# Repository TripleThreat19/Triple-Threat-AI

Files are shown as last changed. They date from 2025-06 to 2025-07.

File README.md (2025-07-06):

# Triple-Threat: Proyecto Orlando 🤖

---

## 🚀 Categoría: Futuros Ingenieros WRO 2025

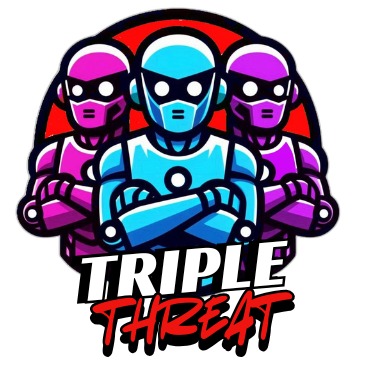
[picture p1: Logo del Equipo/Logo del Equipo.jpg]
Logo del Equipo Triple Threat


---

## 🚀 Presentación del Equipo

Desde que tenemos memoria, la robótica ha sido nuestra pasión. Somos Triple Threat, hermanos trillizos: Carlos, nuestro experto en programación; Valeria, la encargada del diario de ingeniería; y Valentina, la ingeniera mecánica detrás de cada diseño.

Hace dos años, nuestra aventura en la WRO comenzó en la categoría de Deportes Robóticos. No fue cualquier partido, era un tenis doble con una particularidad que lo hacía desafiante: cuatro pelotas en cada lado, una pared en contra y una rampa que agregaba una capa extra de complejidad al campo de juego. Fue un reto estratégico donde aprendimos la importancia de cada detalle, la precisión en el movimiento y la presión del tiempo. El año pasado, la emoción se multiplicó cuando, con mucho esfuerzo y dedicación, logramos clasificar para la etapa internacional en Turquía. Esa experiencia fue inolvidable: conocer a equipos de todo el mundo, sumergirnos en diferentes culturas y, sobre todo, poner a prueba nuestras habilidades en un escenario global.

Ahora, después de esas dos increíbles experiencias, queríamos un nuevo desafío, algo que nos llevara al límite. Queríamos medir hasta dónde hemos crecido, no solo individualmente, sino como equipo. Por eso, decidimos inscribirnos en la categoría de Futuros Ingenieros. Este no es solo otro concurso para nosotros; es la oportunidad perfecta para aplicar todo lo que hemos aprendido, para innovar, para enfrentarnos a problemas complejos y demostrar que nuestra pasión y nuestro trabajo en equipo son más fuertes que nunca. Queremos ver de qué somos capaces cuando la creatividad, la lógica y la camaradería se unen en un robot que redefine los límites.

---

## 📖 Diario de Ingeniería / Documentación Técnica

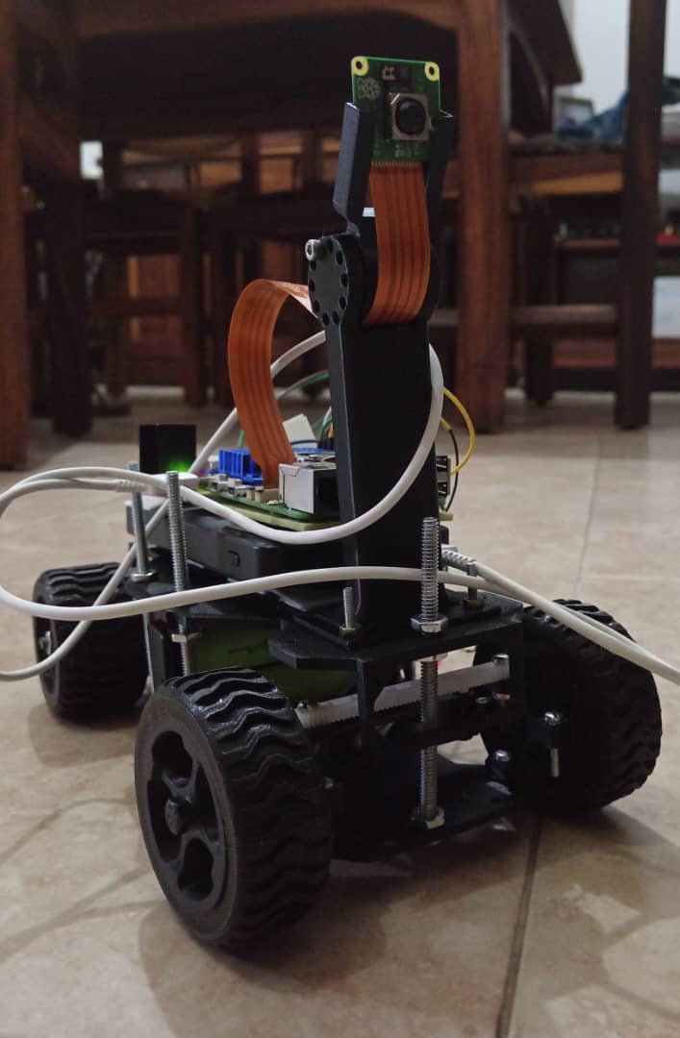
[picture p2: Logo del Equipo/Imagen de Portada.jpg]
Imagen de Portada del Proyecto Orlando (https://github.com/TripleThreat19/Triple-Threat-AI)


Este repositorio centraliza toda la **documentación técnica** del proyecto **Orlando**, una iniciativa desarrollada por el equipo **Triple Threat** para la categoría **Futuros Ingenieros** de la **WRO 2025**. Aquí, desglosamos meticulosamente cada aspecto de nuestro robot: desde el **diseño detallado del vehículo** y la **programación del sistema de control**, hasta la **selección estratégica de componentes** y la **estructura de cableado** implementada para su óptimo funcionamiento.

Cada sección es un reflejo de nuestro **esfuerzo, dedicación y compromiso** como equipo frente a este emocionante desafío. El proyecto Orlando no es solo una solución técnica a un problema propuesto; es el culmen de incontables horas de **trabajo en equipo, investigación profunda, pruebas constantes y mejora continua**, todo impulsado por nuestra **pasión por la robótica y el aprendizaje colaborativo**.

Con este trabajo, nuestro objetivo es doble: no solo buscamos destacar en la competencia, sino también **inspirar a otros jóvenes** a sumergirse en el fascinante mundo de la ingeniería con creatividad, disciplina y un entusiasmo inquebrantable. ¡Esperamos que este diario sea una fuente de aprendizaje y motivación!

---

---

# Problema Identificado: Vehículo Autónomo para Competición "Time Attack" (WRO Futuros Ingenieros)

## Desafío del Reto

El desafío de la **World Robot Olympiad (WRO)** en la categoría de **Futuros Ingenieros** para esta temporada se enfoca en **vehículos autónomos para carreras tipo "Time Attack"**. El objetivo es diseñar, construir y programar un robot capaz de navegar una pista, superar obstáculos específicos y realizar un estacionamiento en paralelo, todo ello buscando el mejor tiempo posible.

## Problemas Clave a Resolver

Hemos identificado los siguientes desafíos técnicos principales que nuestro vehículo debe superar:

### 1. Navegación y Control de Alta Velocidad
* **Seguimiento de Pista Preciso:** El robot necesita un sistema robusto para mantenerse dentro de la pista y seguir la línea con gran exactitud durante múltiples vueltas, optimizando la trayectoria para la velocidad.
* **Control Dinámico de Velocidad:** Mantener la máxima velocidad posible sin perder el control en curvas o secciones complejas es crucial para el "Time Attack".

### 2. Adaptación a Obstáculos Variables

#### Desafío de Muros Interiores Aleatorios:
* **Detección de Muros en Tiempo Real:** El robot debe identificar la posición cambiante de los muros en la pista sin depender de un mapa predefinido.
* **Evasión Eficiente:** Desarrollar algoritmos que permitan al robot rodear los muros rápidamente y sin colisionar, recalculando su ruta sobre la marcha.

#### Desafío de Señales de Tráfico (Pilares Verdes/Rojos):
* **Reconocimiento Visual de Señales:** Implementar un sistema fiable para detectar y diferenciar los pilares verdes (girar a la izquierda) y rojos (girar a la derecha).
* **Decisión y Maniobra Basada en Señal:** El robot debe ajustar su posición en el carril según la señal detectada, ejecutando la maniobra con precisión para no desplazar los pilares.

### 3. Maniobra de Estacionamiento en Paralelo
* **Detección de Zona de Aparcamiento:** El robot necesita identificar el espacio de estacionamiento designado al finalizar las vueltas.
* **Ejecución Precisa del Paralelo:** Realizar una secuencia compleja de movimientos coordinados para estacionar el vehículo correctamente en un espacio reducido.

---

## 🎯  Nuestro Enfoque

Nuestro proyecto busca desarrollar un vehículo autónomo que integre **percepción avanzada del entorno, toma de decisiones dinámica y control de movimiento de alta precisión**. Para lograr esto, utilizaremos una **cámara Raspberry Pi AI** para el procesamiento visual y la detección de elementos clave en la pista, conectada a una **Raspberry Pi** que actuará como el cerebro principal para la lógica de control, la planificación de trayectoria y la ejecución de maniobras. Esta combinación nos permitirá abordar eficazmente los desafíos de navegación, adaptación a obstáculos variables y la maniobra final de estacionamiento, con el objetivo de lograr los mejores tiempos en la competición.

---

## 🛠️ Factor de Ingeniería / Diseño del Prototipo

---

## 1. Mecánica del Robot

El diseño mecánico se enfoca en una estructura **robusta y ligera**, optimizada para la distribución del peso y la integración de todos los componentes electrónicos y motrices.

### 1.1. Componentes Clave

* **Chasis**: Es la base del robot. Su diseño está pensado para soportar todos los componentes y asegurar la **rigidez estructural**. La forma y el material (generalmente polímeros resistentes o aleaciones ligeras, según el **modelo 3D**) se seleccionan según la aplicación específica del robot.

* **Tren de Rodaje**: Se compone de un mínimo de cuatro ruedas. Las **ruedas delanteras** son las encargadas de la **dirección**, mientras que las **ruedas traseras** actúan como propulsoras, brindando el empuje necesario para el movimiento. 

---

## 2. Sistema de Dirección

El sistema de dirección es fundamental para la **maniobrabilidad** del robot, imitando el principio de un automóvil. Se basa en el movimiento angular de las **ruedas delanteras**.

### 2.1. Componentes Principales

* **Ruedas Delanteras Direccionales**: Estas ruedas giran alrededor de un eje vertical (similar al pivote de dirección de un coche) para modificar la trayectoria del robot. Ambas **ruedas delanteras direccionales** están interconectadas y se mueven en un ángulo coordinado gracias a un **mecanismo de dirección**.

* **Mecanismo de Dirección**: Este sistema, detallado en el **modelo 3D**, es una simple barra de acoplamiento que conecta ambas ruedas delanteras
  
* **Servomotor**: Un servomotor de alta precisión, es el responsable de ejecutar el movimiento angular de las **ruedas delanteras direccionales**. Este motor recibe las señales de control de la tarjeta controladora (Rasberry PI) y las traduce en el ángulo de giro deseado. La correcta ubicación y el acoplamiento de este servomotor con el mecanismo de dirección son aspectos críticos en el diseño **3D** para garantizar un movimiento fluido y sin holguras.

* **Rasberry PI 5**: La tarjeta controladora del robot Rasberry PI 5 es la encargada de enviar las señales al servomotor para ajustar el ángulo de las **ruedas delanteras direccionales**. Este controlador puede recibir entradas de la Camara Rasberry PI AI para determinar la dirección que se desea tomar.

---

## 3. Funcionamiento General

Para que el robot pueda moverse y girar eficientemente, el sistema opera de la siguiente manera:

* **Propulsión**: Los motores acoplados a las **ruedas traseras** (o un motor diferencial para ambas) giran para impulsar el robot hacia adelante o hacia atrás. La velocidad se regula mediante la potencia suministrada a estos motores.

* **Dirección**: Para iniciar un giro, la Rasberry PI 5 envía una señal al **servomotor**. El servomotor, a su vez, activa el mecanismo de dirección, lo que provoca el cambio en el ángulo de las **ruedas delanteras direccionales**. El grado de giro de estas ruedas determina directamente el radio de giro del robot.

* **Coordinación**: La clave para un movimiento óptimo reside en la **coordinación** entre la velocidad de las ruedas propulsoras y el ángulo de las **ruedas delanteras direccionales**. Para ejecutar giros cerrados, las ruedas delanteras se angulan más, y la velocidad de las ruedas traseras puede ajustarse para facilitar la maniobra y asegurar un giro suave y controlado.

---

Este diseño, meticulosamente modelado en **3D**, permite una visualización detallada y una optimización exhaustiva de la ergonomía, la resistencia y la funcionalidad del robot antes de proceder con su construcción física. Esto asegura un rendimiento óptimo en todos los aspectos de su mecánica y dirección.

---

## Debate Técnico sobre la Gestión de la Movilidad

### 1. Selección e Implementación de Motores

Para la propulsión del robot utilicé un motor DC con encoder, ya que me permite medir la velocidad angular y la posición de cada rueda, lo cual es clave para controlar con precisión la trayectoria. Este motor se seleccionó por su buen equilibrio entre par (torque) y velocidad para una plataforma de tamaño medio (~1.5 a 2 kg de peso total).

El encoder facilita técnicas de control como PID, permitiendo mantener una velocidad constante incluso con cambios en el terreno o peso del robot.

Para el sistema de dirección utilicé un servomotor de rotación limitada (180°). Este tipo de actuador me permite posicionar con precisión las ruedas delanteras en distintos ángulos, lo que se traduce en giros más suaves y exactos. Elegí un servo de alto torque (más de 10 kg·cm), suficiente para girar ambas ruedas mediante la barra de acoplamiento sin generar vibraciones o juego mecánico.

### 2. Principios de Ingeniería Aplicados

- Velocidad:Se estimó una velocidad objetivo de 0.5 a 1 m/s, adecuada para pruebas y recorridos controlados en escenarios de competencia.
- Par (torque): Los motores deben superar la inercia del robot y el rozamiento del suelo. Para eso, se eligió un motor con un torque mínimo de 2 kg·cm en las ruedas traseras.
- Potencia: La potencia eléctrica se dimensionó en función del consumo del motor DC (~6W por motor) y el servomotor (~2-3W en carga), permitiendo alimentar el sistema con una batería Li-ion de 7.4V.

### 3. Diseño y Selección del Chasis

El chasis fue diseñado en CAD 3D para ser liviano, resistente y fácil de imprimir en una impresora 3D FDM. Utilicé PLA reforzado como material principal por su buena relación rigidez/peso. La forma del chasis favorece la distribución de peso centrada, con espacio suficiente para el servo, motores, controlador y batería.

### 4. Montaje de Componentes

- El chasis impreso contiene ranuras específicas para montar los motores DC y sus reductoras usando tornillos M3.
- El servo de dirección se acopla con dos tornillos a un soporte elevado en el centro del eje delantero.
- Las ruedas delanteras están conectadas por una barra rígida impresa en 3D que transmite el movimiento angular del servo.
- La Raspberry Pi 5, el controlador motor y la batería se fijan al chasis mediante bridas plásticas o tornillos autorroscantes en zonas ya previstas en el diseño.

---

### Control del Movimiento (Actuadores):

Motores Modificadores Ópticos Makeblock 180: Estos motores son los encargados de la propulsión del robot, conectados a las ruedas traseras. Incluyen codificadores ópticos que nos dan retroalimentación precisa sobre la velocidad y la distancia recorrida, información vital para la odometría y un control de movimiento exacto.

Puente H: Funciona como la interfaz de potencia entre la Raspberry Pi 5 y los motores Makeblock 180. Permite a la Pi controlar la dirección y la velocidad de los motores (mediante PWM) con señales de bajo voltaje.

Servomotor (Dirección): Este servomotor es crucial para el control preciso del ángulo de las ruedas delanteras directrices. La Raspberry Pi 5 le envía señales PWM para posicionar las ruedas con exactitud, permitiendo giros controlados y suaves.

Percepción del Entorno (Sensores):

Raspberry Pi AI Camera: Este es el principal sensor visual del robot. Conectada a la Raspberry Pi 5, nos permite implementar visión por computadora y algoritmos de Inteligencia Artificial. La cámara procesa el entorno para:

Detección y Reconocimiento de Objetos: Identifica obstáculos, marcas o elementos clave en el entorno.

Seguimiento de Trayectorias: Percibe líneas o caminos a seguir.

Análisis Espacial: Comprende la profundidad y la disposición de los elementos.
La potente Raspberry Pi 5 puede procesar estos datos de imagen en tiempo real, permitiendo al robot tomar decisiones informadas sobre su navegación y acciones.

Software de Control: Todo el sistema lo gestiona el software que se ejecuta en la Raspberry Pi 5, desarrollado principalmente en Python. Este software integra las lecturas de los codificadores y la cámara, procesa la información y genera las señales de control para el Puente H y el servomotor, coordinando así todos los aspectos del movimiento y la interacción del robot con su entorno.

---

# 🤖 Sistema de Rueda y Eje para Nuestro Robot ⚙️

¡Bienvenidos a la sección de hardware de nuestro proyecto! Aquí explicaremos cómo se ensamblan las piezas clave para el movimiento de nuestro robot. La imagen de arriba muestra un "despiece" de los componentes esenciales que conforman una de las unidades de rueda.

---

### Visión General del Ensamblaje

Este sistema está diseñado para proporcionar una rotación fluida y robusta, fundamental para la locomoción de nuestro robot. Cada componente juega un papel crucial en la durabilidad y eficiencia del movimiento.

Es importante destacar que este diseño en particular está pensado para las ruedas delanteras de nuestro robot, actuando como las ruedas directrices. Esto significa que estas unidades serán responsables de la dirección del vehículo. Las ruedas traseras, por su parte, serán las que vayan impulsadas directamente por un motor, complementando este sistema para mejorar significativamente la movilidad y la capacidad de maniobra de nuestro vehículo.

---

### Desglose del Proceso de Montaje

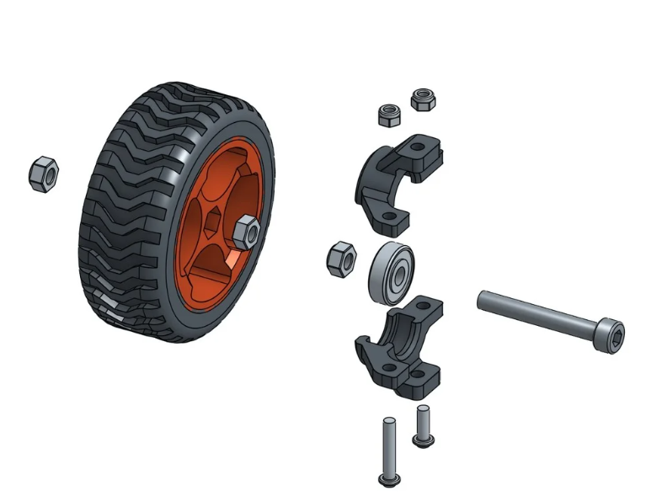
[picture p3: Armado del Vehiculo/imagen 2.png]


El montaje de este subsistema se concibe en una secuencia lógica que asegura la correcta funcionalidad y alineación de las partes:

1.  **Eje y Rodamiento:**
    El punto de partida es el **eje**, un elemento central sobre el cual se montará el **rodamiento**. Este rodamiento es una pieza ingenieril clave, cuya función principal es minimizar la fricción, permitiendo que el eje (y, por ende, la rueda) gire con la mayor suavidad posible y con un mínimo desgaste.

2.  **Soporte del Rodamiento:**
    Una vez que el rodamiento está posicionado en el eje, ambos se alojan dentro del **soporte de rodamiento**. Este soporte se compone de dos mitades que se unen, encapsulando y asegurando el rodamiento en su lugar. La unión de estas dos secciones se logra mediante el uso de **tornillos y tuercas más pequeños**, garantizando que el rodamiento quede firmemente contenido, pero con libertad para girar sobre el eje.

3.  **Fijación de la Rueda:**
    Con el eje y el conjunto de rodamiento/soporte listos, la **rueda** se desliza sobre el extremo libre del eje. Para asegurar que la rueda no se desplace ni se suelte durante el funcionamiento de nuestro robot, se utiliza una **tuerca adicional** que se rosca firmemente en el extremo del eje, fijando la rueda en su posición adecuada.

4.  **Integración en el Chasis del Robot:**
    Finalmente, este ensamblaje completo (compuesto por la rueda, el eje, el rodamiento y su soporte) se integra directamente en la estructura principal de nuestro robot. El diseño del **soporte de rodamiento** incluye puntos de montaje que permiten su fijación segura al chasis o a los brazos de suspensión, si los tuviera. Esta integración no solo proporciona el anclaje físico, sino que también establece el punto de pivote exacto para la rotación de la rueda, siendo esencial para la dinámica de movimiento de nuestro robot.

---

# 🤖 Distribución de Componentes en el Chasis del Robot ⚙️

Nuestro chasis ha sido meticulosamente diseñado para una distribución específica de componentes, buscando optimizar el centro de gravedad y facilitar el proceso de montaje. A continuación, detallamos la ubicación estratégica de los elementos principales:

---

### Colocación de Componentes Clave en la Primera Placa:

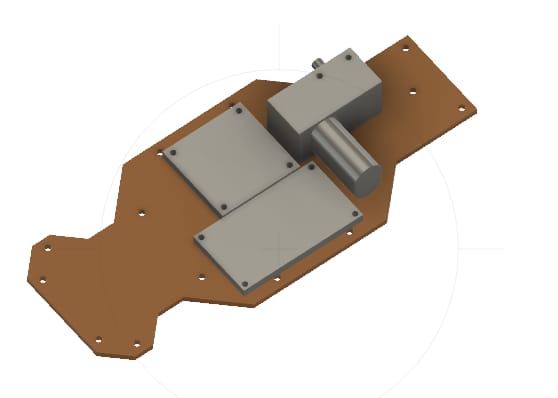
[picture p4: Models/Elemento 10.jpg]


* **Motor:** Se ubica y fija en la parte trasera del chasis. Esta posición estratégica ayuda a concentrar el peso, optimizando la tracción y el balance general del robot.

* **Baterías (Pilas):** Se colocan centralmente en el chasis y se aseguran mediante tornillos. Esta disposición es crucial para lograr una distribución equilibrada del peso, lo que mejora significativamente la estabilidad y la maniobrabilidad del vehículo.

* **Regulador de Voltaje (Regulador):** Aunque no es visible en la disposición general, se situará típicamente cerca de las baterías. Su función es regular el voltaje de entrada para alimentar de forma estable y segura el resto de la electrónica de control del robot.

* **Puente H:** Este componente clave se colocará lo más próximo al motor posible. Esta cercanía minimiza la longitud del cableado, lo que reduce las pérdidas de energía y optimiza el control de dirección y velocidad del motor.

* **Servomotor: Este componente se ubicará en la parte delantera del chasis. Su función principal es controlar el mecanismo de dirección de las ruedas delanteras, permitiendo al robot cambiar de trayectoria con precisión
---

🤖 Ensamblaje del Robot: Distribución de Componentes en el Chasis ⚙️
Nuestro chasis ha sido meticulosamente diseñado para una distribución estratégica de componentes, buscando optimizar el centro de gravedad, la funcionalidad y la facilidad de montaje. A continuación, detallamos la ubicación pensada para los elementos clave:

---

Disposición de Componentes de Percepción y Procesamiento (Segundo Piso):

Estos componentes vitales para la inteligencia y operación del robot se alojarán en una placa superior o "segundo piso", que se montará sobre el chasis principal, aprovechando estructuras como las mostradas en "Elemento 11.jpg".

---

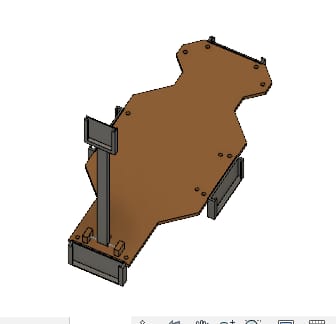
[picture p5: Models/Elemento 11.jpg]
)

Soporte Frontal Vertical (Cámara y Módulo): Esta estructura, parte del segundo piso o conectada a él, está diseñada específicamente para montar la cámara y su módulo adicional en la parte frontal elevada. Su posición estratégica garantiza un campo de visión despejado y alto, crucial para tareas como la detección de obstáculos, navegación y mapeo ambiental.

Espacio Inferior del Segundo Piso (Raspberry Pi y Puente H): En la zona inferior de este segundo nivel (o sobre la superficie de esta placa superior) se destinará el espacio para el Powerbank y la Raspberry Pi. Esta ubicación es fundamental para mantener el "cerebro" del robot (Raspberry Pi) y su fuente de energía suplementaria (Powerbank) accesibles, a la vez que se optimiza el cableado y se minimiza la altura total, contribuyendo al centro de gravedad general del conjunto.

---

# Electrónica

---

Nuestro sistema electrónico, que impulsa y controla cada movimiento de nuestro robot, está cuidadosamente ensamblado con los siguientes elementos clave:
-	Raspberry Pi 5
-	Raspberry Pi AI Camera
-	Servomotor
-	Motor Modificador Óptico Makeblock 180
-	Puente H
- Regulador de Voltaje
-	Baterías
-	Switch
-	Power Bank 

A continuación, se presentará el Diagrama de Cableado que ilustra cómo estos componentes se interconectan para funcionar en armonía.

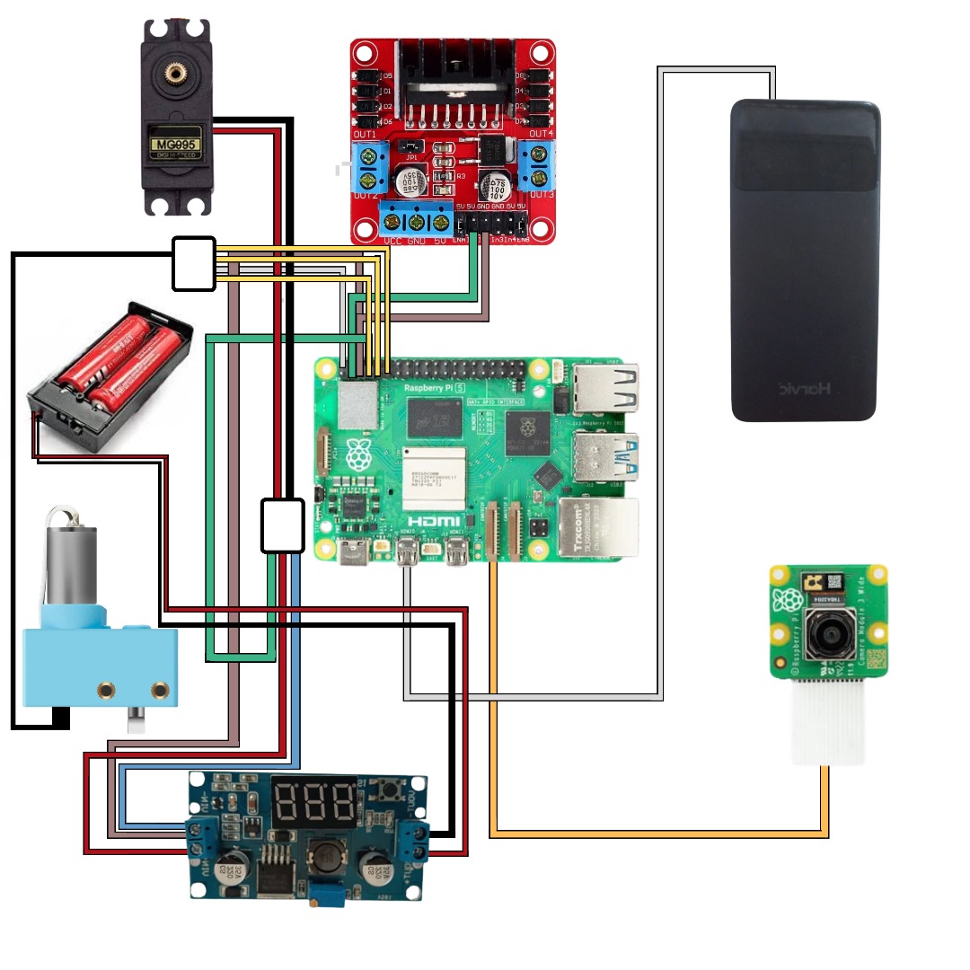
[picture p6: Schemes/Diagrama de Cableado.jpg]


Explicación del Diagrama Expuesto

Raspberry Pi: Es la computadora principal del sistema. Recibe información de algunos componentes y envía órdenes a otros.

Power Bank: Este es la fuente de energía exclusiva para la Raspberry Pi. Le suministra la electricidad necesaria para funcionar.

Baterías: Estas baterías son la fuente de energía exclusiva para los motores. Suministran electricidad al Módulo Regulador de Voltaje y al Módulo de Driver de Motor.

Módulo de Driver de Motor: Este módulo se conecta a la Raspberry Pi (para recibir órdenes) y a las baterías (para obtener energía). Se usa específicamente para controlar el motor DC con encoder.

Servo Motor: Este motor puede moverse a posiciones específicas y se controla a través del drive.

Motor DC con Encoder: Este es un motor que gira continuamente, y el "encoder" le permite a la Raspberry Pi saber exactamente qué tan rápido está girando o qué posición tiene. También se controla a través del driver del motor.

Módulo Regulador de Voltaje: Este módulo toma la energía de las baterías (las rojas) y la ajusta a un voltaje específico que necesita el servomotor, asegurando que reciba la cantidad correcta de energía de manera estable. 

Cámara: Esta cámara se conecta directamente a la Raspberry Pi. Permite a la Raspberry Pi "ver" y capturar imágenes o video.

****
---

### 💡 Componentes del Vehículo

Hemos seleccionado cuidadosamente cada componente para asegurar el máximo rendimiento y fiabilidad de nuestro robot. A continuación, detallamos los elementos esenciales que dan vida a nuestro proyecto.

#### 🧠 Raspberry Pi 5

La **Raspberry Pi 5** es el cerebro de nuestro sistema, definida por la misma Raspberry Pi Foundation como una **PC de bajo coste del tamaño de una tarjeta de crédito**. Permite explorar el mundo de la informática y aprender lenguajes de programación como Scratch y Python, siendo una herramienta increíblemente versátil.

---
**_Características Destacadas:_**

* **CPU de alto rendimiento:** Procesador Broadcom BCM2712 Quad-core Arm Cortex-A76 a 2.4 GHz, ofreciendo un gran poder de procesamiento.
* **GPU avanzada:** GPU VideoCore VII para capacidades gráficas y de procesamiento de visión mejoradas.
* **Memoria RAM generosa:** Disponible con hasta 8GB de RAM LPDDR4X-4267, ideal para multitarea y aplicaciones exigentes.
* **Conectividad versátil:** Incluye Wi-Fi 5 de doble banda, Bluetooth 5.0 y Gigabit Ethernet para una comunicación robusta.
* **Almacenamiento de alta velocidad:** Soporte para tarjetas microSD de alta velocidad y una interfaz PCIe 2.0 x1 para SSDs M.2 externos (vía adaptador).
* **Salida de video dual:** Dos puertos micro HDMI que soportan hasta 4K a 60Hz.
* **Puertos USB 3.0:** Dos puertos USB 3.0 para conectar periféricos de alta velocidad.
* **Conectores MIPI duales:** Dos transceptores MIPI de 4 carriles para hasta dos cámaras o pantallas.
* **Control de ventilador:** Conector dedicado para un ventilador PWM, asegurando un rendimiento óptimo bajo cargas intensas.

---

La **Raspberry Pi 5** es ideal para nuestro robot por su **gran potencia de procesamiento para IA y visión**, lo que nos permite implementar algoritmos complejos. Su **amplia RAM** asegura una multitarea eficiente y su **conectividad avanzada** facilita la comunicación. Además, el **almacenamiento SSD ultrarrápido** y los **conectores MIPI duales para cámaras** son fundamentales para la percepción y toma de decisiones en tiempo real, garantizando un robot de **alto rendimiento y gran fiabilidad**.

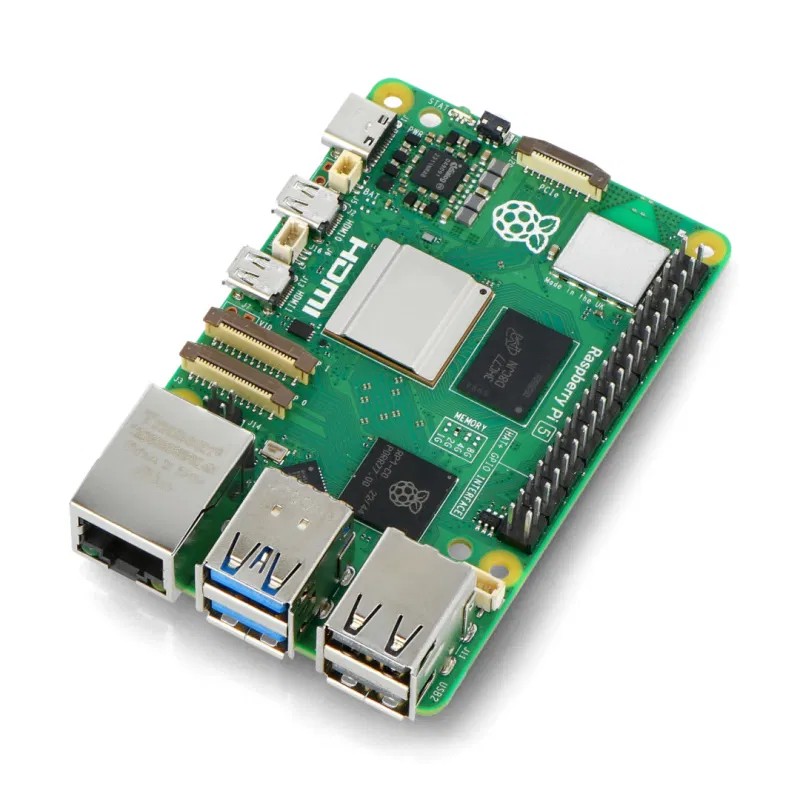
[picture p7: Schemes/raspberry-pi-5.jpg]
Raspberry Pi 5


#### 🔌 Puente H

Un **Puente H** es un circuito electrónico crucial que nos permite **invertir la polaridad de la tensión** aplicada a una carga, comúnmente un motor de corriente continua. Esto se logra mediante la disposición de cuatro interruptores (transistores o relés) que permiten el flujo de corriente en dos direcciones opuestas, controlando así el sentido de giro del motor.

---
**_Características Esenciales:_**

* **Control del sentido de giro:** Permite invertir la polaridad del voltaje aplicado a un motor codificador Óptico, facilitando su rotación hacia adelante o hacia atrás.
* **Control de velocidad:** Al integrar una señal de Modulación por Ancho de Pulso (PWM), puede variar la velocidad del motor de manera eficiente.
* **Capacidad de corriente y voltaje:** Cada Puente H está diseñado para manejar un rango específico, crucial para que coincida con los requisitos del motor y evitar daños.
* **Protecciones integradas:** Muchos puentes H comerciales incluyen protecciones contra sobrecorriente, cortocircuitos y sobrecalentamiento, aumentando la seguridad y durabilidad.
* **Compatibilidad con microcontroladores:** Son fácilmente controlables por microcontroladores como la Raspberry Pi o Arduino, simplificando la lógica de control del motor.
* **Aislamiento y protección del microcontrolador:** Actúa como una interfaz de potencia, protegiendo los componentes de control sensibles de las altas corrientes y ruidos generados por el motor.

---

El **Puente H** es fundamental para nuestro robot porque permite el **control total del motor**: puede cambiar el sentido de giro (adelante/atrás) y, con PWM, controlar la velocidad con precisión. Además, actúa como un **escudo protector para el motor**, aislando los componentes sensibles y garantizando la fiabilidad y seguridad del sistema.

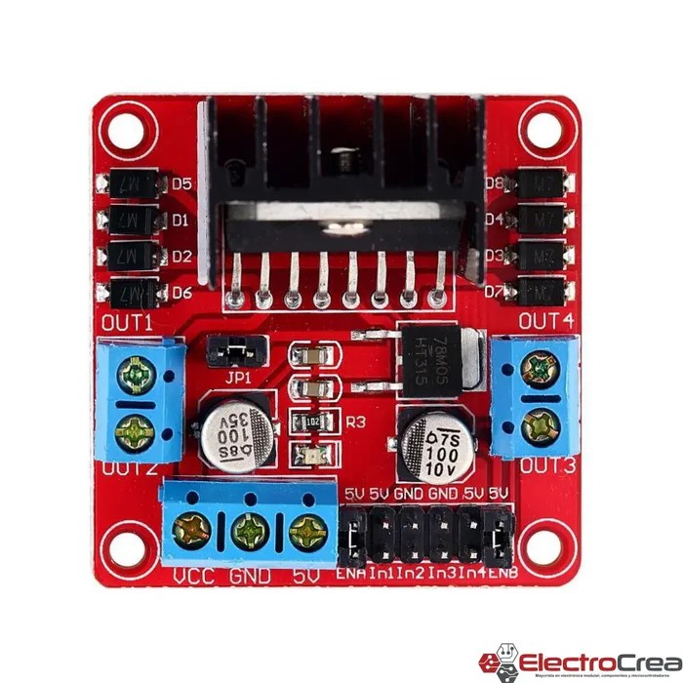
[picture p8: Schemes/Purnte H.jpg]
Puente H


#### 📸 Raspberry Pi AI Camera

La **Raspberry Pi AI Camera** está específicamente diseñada para aprovechar el **procesamiento avanzado de inteligencia artificial (IA)** en dispositivos Raspberry Pi, especialmente cuando se combina con hardware de aceleración como el Hailo AI Module.

---
**_Características Sobresalientes:_**

* **Procesamiento de IA en el chip (Edge AI):** Realiza la inferencia de redes neuronales directamente en el sensor Sony IMX500, liberando la Raspberry Pi principal de esta carga computacional. Esto permite IA en tiempo real con baja latencia.
* **Sensor de alta resolución:** Cuenta con un sensor de 12.3 megapíxeles (4056 x 3040 píxeles), capturando imágenes detalladas.
* **Salida de metadatos de tensor:** Además de la imagen, la cámara puede enviar directamente los resultados del procesamiento de IA, simplificando la integración con otras aplicaciones.
* **Compatibilidad y enfoque manual:** Se conecta vía CSI estándar con todas las Raspberry Pi compatibles y permite ajustar manualmente el enfoque para diversas aplicaciones.
* **Reducción de latencia y ancho de banda:** Los datos procesados de IA (como la detección de objetos) se generan directamente en la cámara, minimizando la latencia y reduciendo significativamente el ancho de banda necesario en el bus de datos CSI.

---

La **Raspberry Pi AI Camera** es fundamental para nuestro robot porque permite la **IA en el borde**, procesando visión directamente en el chip. Esto libera recursos de la Pi 5, reduce la latencia y la necesidad de ancho de banda. Su **alta resolución** y la capacidad de enviar **metadatos de IA pre-procesados** simplifican el desarrollo. Además, es **energéticamente eficiente**, clave para la autonomía del robot. En definitiva, convierte a nuestro robot en un agente **inteligente y reactivo** capaz de percibir e interpretar su entorno de forma autónoma.

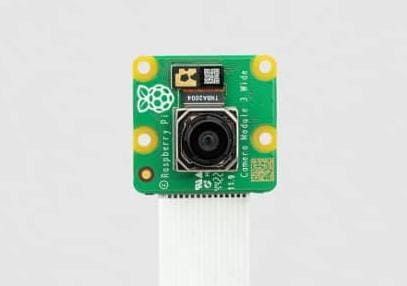
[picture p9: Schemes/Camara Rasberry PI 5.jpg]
La Raspberry Pi AI Camera


(AC) convencionales por su capacidad de **controlar con precisión su posición angular, velocidad y, en algunos casos, su aceleración**. Piensa en él como un motor que no solo gira, sino que sabe exactamente dónde está y puede ir a una posición específica y mantenerla, incluso si hay una fuerza externa que intenta moverlo.

---

Servomotor
Un servomotor es un tipo de motor especial que se diferencia de los motores de corriente continua (DC) o alterna (AC) convencionales por su capacidad de controlar con precisión su posición angular, velocidad y, en algunos casos, su aceleración. Piensa en él como un motor que no solo gira, sino que sabe exactamente dónde está y puede ir a una posición específica y mantenerla, incluso si hay una fuerza externa que intenta moverlo.

---

**_Características Principales:_**

* **Control de Posición Preciso:** Esta es su característica principal. A diferencia de un motor DC que gira libremente cuando se le aplica voltaje, un servomotor puede ser instruido para moverse a un ángulo específico (por ejemplo, 45 grados, 90 grados, etc.) y mantenerse allí.
* **Sistema de Lazo Cerrado:** Un servomotor siempre forma parte de un sistema de "lazo cerrado". Esto significa que tiene un mecanismo de retroalimentación (generalmente un potenciómetro o un encoder) que constantemente informa al controlador sobre la posición actual del eje del motor. El controlador compara esta posición con la posición deseada y ajusta la energía al motor para corregir cualquier desviación.
* **Componentes Internos:**
    * **Motor DC o AC:** El motor eléctrico real que genera el movimiento.
    * **Engranajes reductores:** Un sistema de engranajes que reduce la velocidad del motor pero aumenta su torque (fuerza de giro), permitiendo movimientos más controlados y con mayor fuerza.
    * **Sensor de Posición (Potenciómetro/Encoder):** Mide la posición actual del eje del motor y envía esta información al controlador.
* **Tipos de Señal de Control:** Generalmente se controlan mediante señales de Modulación por Ancho de Pulso (PWM). La duración del pulso determina la posición a la que debe moverse el servomotor.

---

El **servomotor** es crucial para nuestro robot porque permite un **control de posición angular preciso**, a diferencia de los motores DC simples. Esto es fundamental para que el robot realice **movimientos exactos y articulados**, como orientar cámaras o manipular objetos. Su sistema de lazo cerrado y el control por PWM simplifican la programación de movimientos complejos, asegurando que el robot interactúe con su entorno de forma controlada y efectiva.

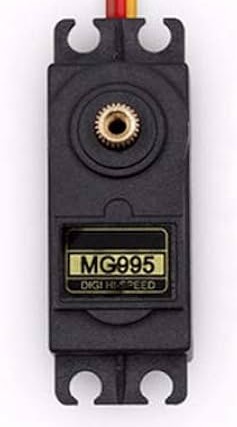
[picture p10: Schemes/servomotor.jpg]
Servomotor


#### ⚡ Regulador de Voltaje

Un **regulador de voltaje electrónico** en robótica es un componente crucial diseñado para **mantener una tensión eléctrica de salida constante y estable** para los distintos sistemas del robot, sin importar las variaciones en la fuente de alimentación (como una batería que se descarga) o los cambios en la demanda de energía de los componentes del robot.

---
**_Características Esenciales:_**

* **Estabilización de la Tensión de Suministro:** Su función principal es vital para un robot. Asegura que la Raspberry Pi, los servomotores y los sensores reciban el voltaje exacto que necesitan (por ejemplo, 5V para la Pi), incluso si la batería del robot comienza a descargarse y su voltaje total disminuye. Esto es crucial para la estabilidad y fiabilidad del sistema.
* **Manejo de Diferentes Niveles de Voltaje:** Un robot suele tener varios componentes que operan a diferentes voltajes (ej. 5V para la lógica, 12V para los motores). Los reguladores permiten crear "rieles" de voltaje específicos a partir de una única fuente de alimentación, simplificando el diseño del sistema de energía.
* **Eficiencia Energética (para Robots Autónomos):** En robótica, la eficiencia es fundamental para la autonomía. Los reguladores conmutados (switching) son preferidos en robots. Son mucho más eficientes que los lineales, ya que minimizan la energía que se pierde como calor. Esto significa que la batería del robot durará más tiempo, aumentando su autonomía operativa.
* **Versatilidad:** Pueden ser reductores (buck) para bajar el voltaje de la batería (ej. de 12V a 5V para la Pi) o incluso elevadores (boost) si un componente necesita un voltaje mayor que el de la batería.

---

El **Regulador de Voltaje Electrónico** es indispensable para el robot porque asegura una **alimentación eléctrica constante y estable** específicamente para el/los servomotor(es). Es vital para:

* **Proteger los servomotores:** Garantiza que reciban siempre el voltaje óptimo, previniendo daños por fluctuaciones de la batería o picos de carga.
* **Asegurar su rendimiento preciso:** Un voltaje estable es clave para el funcionamiento fiable y la precisión de movimiento del/de los servomotor(es).
* **Maximizar la autonomía:** Al usar reguladores conmutados eficientes, minimiza la pérdida de energía en la alimentación del/de los servomotor(es), prolongando la duración de la batería del robot.

En esencia, el regulador es fundamental para la **fiabilidad y la prolongación de la vida útil** de los componentes eléctricos del robot.

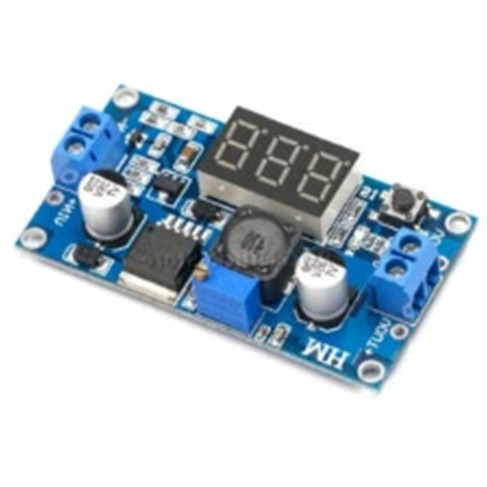
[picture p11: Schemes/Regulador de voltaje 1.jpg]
Regulador de Voltaje


#### ⚙️ Motor Codificador Óptico Makeblock 180

El **Motor Codificador Óptico Makeblock 180** es un tipo de motor DC (corriente continua) que incorpora un **codificador óptico** en su diseño. Esto lo convierte en un componente clave para aplicaciones de robótica y automatización donde se requiere un **control de movimiento preciso y con retroalimentación**.

---
**_Características Destacadas:_**

* **Motor DC con Engranajes:** Esencialmente, es un motor de corriente continua con una caja reductora de engranajes (con una relación de reducción de 39.6). Esto significa que el motor, aunque gira a altas RPM internamente (hasta 14,000 RPM sin carga), su eje de salida gira a una velocidad mucho menor (350 RPM sin carga), pero con un **par (torque) significativamente mayor** (800 g·cm nominal, 5 kg·cm de arranque). Este alto torque es fundamental para mover ruedas o cargar estructuras en un robot.
* **Codificador Óptico Integrado:** Esta es la característica más importante y lo que lo diferencia de un motor DC estándar. Un codificador óptico utiliza un disco ranurado y un sensor de luz para detectar el movimiento rotatorio del eje del motor. A medida que el disco gira, interrumpe un haz de luz, generando pulsos eléctricos.
* **Precisión de Detección:** El codificador óptico del Makeblock 180 tiene una **precisión de detección de 1°**, lo que permite un control muy fino.
* **Retroalimentación:** Al contar estos pulsos, un microcontrolador (como la Raspberry Pi) puede saber con precisión la **posición angular exacta del eje del motor, la velocidad de rotación y la distancia recorrida** (si está conectado a una rueda).
* **Construcción Robusta y Reducción de Ruido:** Makeblock ha diseñado este motor con materiales personalizados que ayudan a reducir el ruido durante su funcionamiento. Además, cuenta con un eje de salida de acero para una mayor durabilidad y una caja de engranajes de materiales POM (polioximetileno) que son antiabrasivos.

---

El **Motor Codificador Óptico Makeblock 180** es fundamental para nuestro robot porque ofrece un **control de movimiento preciso y con retroalimentación**. Su codificador óptico permite a la Raspberry Pi 5 conocer exactamente la posición, velocidad y distancia recorrida, lo cual es indispensable para una **navegación autónoma exacta, control de movimiento fino** (giros y paradas precisas), detección de bloqueos y una **mayor fiabilidad y repetibilidad** en sus desplazamientos. Transforma al robot en un sistema de **navegación inteligente y confiable**.

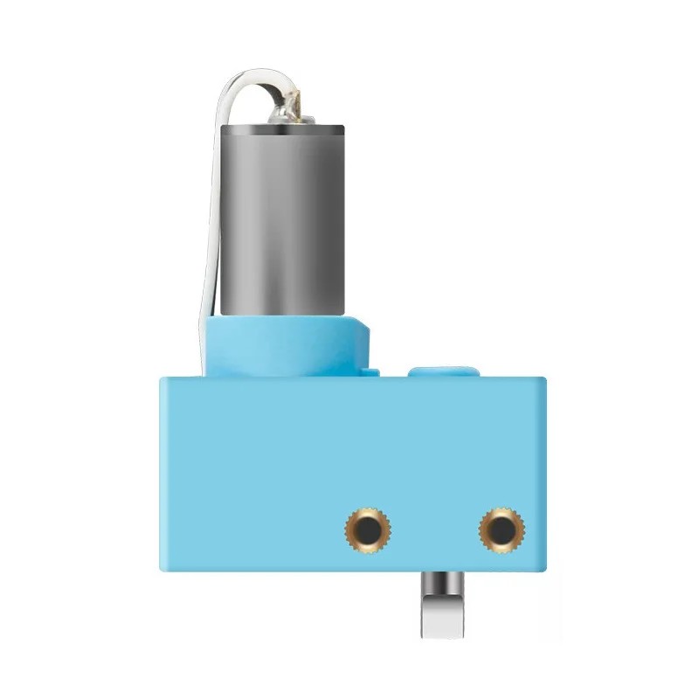
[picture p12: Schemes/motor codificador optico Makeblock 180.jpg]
Motor Codificador Optico Makeblock 180


---

---

### 💡 Componentes Clave del Vehículo

Hemos seleccionado cuidadosamente cada componente para asegurar el máximo rendimiento y fiabilidad de nuestro robot. A continuación, detallamos los elementos esenciales que dan vida a nuestro proyecto.

#### 🧠 Raspberry Pi 5

La **Raspberry Pi 5** es el cerebro de nuestro sistema, definida por la misma Raspberry Pi Foundation como una **PC de bajo coste del tamaño de una tarjeta de crédito**. Permite explorar el mundo de la informática y aprender lenguajes de programación como Scratch y Python, siendo una herramienta increíblemente versátil.

La **Raspberry Pi 5** es ideal para nuestro robot por su **gran potencia de procesamiento para IA y visión**, lo que nos permite implementar algoritmos complejos. Su **amplia RAM** asegura una multitarea eficiente y su **conectividad avanzada** facilita la comunicación. Además, el **almacenamiento SSD ultrarrápido** y los **conectores MIPI duales para cámaras** son fundamentales para la percepción y toma de decisiones en tiempo real, garantizando un robot de **alto rendimiento y gran fiabilidad**.

#### 📸 Raspberry Pi AI Camera

La **Raspberry Pi AI Camera** está específicamente diseñada para aprovechar el **procesamiento avanzado de inteligencia artificial (IA)** en dispositivos Raspberry Pi, especialmente cuando se combina con hardware de aceleración como el Hailo AI Module.

La **Raspberry Pi AI Camera** es fundamental para nuestro robot porque permite la **IA en el borde**, procesando visión directamente en el chip. Esto libera recursos de la Pi 5, reduce la latencia y la necesidad de ancho de banda. Su **alta resolución** y la capacidad de enviar **metadatos de IA pre-procesados** simplifican el desarrollo. Además, es **energéticamente eficiente**, clave para la autonomía del robot. En definitiva, convierte a nuestro robot en un agente **inteligente y reactivo** capaz de percibir e interpretar su entorno de forma autónoma.

---

## ⚡ Gestión de la Potencia y los Sensores

# Gestión de Potencia y Control de Sentido del Vehiculo

---

Este documento detalla la estrategia de gestión de potencia y el sistema de control de sentido implementados en nuestro robot, utilizando una Raspberry Pi 5 y la Raspberry Pi AI Camera.

---

## Gestión de Energía y Sensores

Esta sección aborda cómo el vehículo gestiona su energía y sensores para navegar con precisión y eficiencia en los desafíos del entorno. Se detalla la fuente de alimentación, los sensores utilizados, su justificación técnica y el impacto de estos en el comportamiento del robot, así como un resumen del consumo energético.

## 1. Fuente de Energía
El robot utiliza dos fuentes de energía diferenciadas:

- Power Bank USB de 5V 3A: Alimenta exclusivamente a la Raspberry Pi 5, garantizando una alimentación estable y continua. Esta opción es práctica, segura y evita la necesidad de reguladores externos para la Raspberry.

- Batería Li-ion de 7.4V (mínimo 2000 mAh): Alimenta directamente el motor DC con encoder (propulsión) y el servomotor SG90 (dirección). Esta batería está conectada a través de un módulo de control de motor (usando GPIO y PWM desde la Raspberry Pi).

Este enfoque separa las cargas de procesamiento y movimiento, evitando caídas de tensión en la Raspberry Pi debido a picos de corriente de los motores.

Regulador de Voltaje (Buck Converter): Como la Raspberry Pi 5 y la Raspberry Pi AI Camera operan a 5V, y nuestras baterías de litio tienen un voltaje nominal más alto, un regulador de voltaje DC-DC (buck converter) es indispensable. Este componente reduce y estabiliza el voltaje de las baterías a los 5V requeridos, protegiendo la electrónica sensible de sobretensiones y fluctuaciones.

Switch Principal: Un interruptor físico nos permite encender y apagar el robot de forma segura, controlando el flujo general de energía desde las baterías.

## 2. Sensores
El sistema utiliza múltiples sensores y módulos para recopilar información del entorno:

- Cámara Picamera2: Captura video en tiempo real, analiza el entorno mediante visión artificial y detecta colores (negro, azul y naranja) en formato HSV para identificar líneas de guía, obstáculos y realizar conteo de vueltas.

- Encoder en motor DC: Permite medir la rotación del motor, ayudando al conteo de vueltas.
El sistema tiene un pin asignado para un encoder, pero la funcionalidad de conteo de vueltas actual se basa puramente en la visión por computadora.

- Servomotor SG90: Aunque es un actuador, responde constantemente a los comandos del sistema basados en los datos provenientes de los sensores para ejecutar giros precisos.

  ## 3. Consumo de Energía
Se estima el siguiente consumo energético:

- Raspberry Pi 5 (desde Power Bank): ~2.5 A @ 5V
- Motor DC: ~0.8 A @ 7.4V
- Servomotor SG90: ~150 mA @ 5V
- Cámara Picamera2: ~250 mA @ 5V (alimentada por la Raspberry)

El sistema completo requiere una batería con una capacidad mínima de 15 Wh para operar durante una sesión completa.

## 4. Justificación de Selección de Componentes
Los componentes fueron seleccionados por su eficiencia y compatibilidad:

- El motor DC con encoder permite una propulsión controlada y precisa, útil para detectar vueltas sin sensores adicionales.
- El servomotor SG90 proporciona dirección precisa y rápida con bajo consumo energético.
- La cámara permite reducir la cantidad de sensores al detectar colores y obstáculos simultáneamente mediante visión artificial.

El código de control implementado en Python gestiona la interpretación de los datos de los sensores y actúa en consecuencia, ajustando la dirección, velocidad y decisiones del robot según las condiciones del entorno.

---

## 🚗 Gestión de Movilidad

Este robot, diseñado en 3D, se mueve como un coche: sus ruedas traseras lo impulsan y las ruedas delanteras directrices lo guían. Su diseño mecánico, detallado en el modelo 3D, busca ser robusto y ligero, con espacio para todos los componentes.

La dirección es clave: un servomotor mueve las ruedas delanteras, controlando los giros mediante un mecanismo de dirección (tipo Ackerman). Un controlador coordina estos movimientos para lograr una maniobrabilidad precisa. En resumen, es un vehículo ágil, diseñado para el control exacto de su trayectoria..

---
# *Lenguaje de Programación*

---

# Detección de Objetos y Límites de Pista 🤖
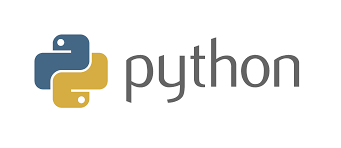
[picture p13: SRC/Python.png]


Para capacitar a nuestro robot con la habilidad de "ver" su entorno, integramos un conjunto de sensores clave. Si bien los sensores de proximidad (como los ultrasónicos o infrarrojos) son cruciales para detectar obstáculos cercanos y medir distancias, el componente central de nuestra visión es la Cámara Raspberry Pi AI.

La Cámara Raspberry Pi AI, en combinación con algoritmos de visión por computadora desarrollados en Python, aprovecha librerías potentes como OpenCV para el procesamiento avanzado de imágenes. Esta sinergia nos permite no solo identificar la presencia de obstáculos, sino también clasificarlos eficazmente, ya sean conos u otros elementos estáticos presentes en el entorno de la pista. La información obtenida de esta detección es indispensable para que el robot tome decisiones de navegación precisas, como la desaceleración o la evasión.

Paralelamente, para asegurar que el robot se mantenga dentro de su trayectoria, utilizamos la Cámara Raspberry Pi AI para el reconocimiento de los bordes de la pista. A través del procesamiento de imágenes en Python, el sistema analiza las características visuales de la pista, incluyendo líneas y paredes, permitiendo al robot ajustar su dirección de forma continua para permanecer dentro de los límites predefinidos.

# DIAGRAMAS DE LOS CODIGOS 

----

Este documento presenta los diagramas de código de nuestro prototipo de robot, donde este esquivara las paredes tanto internas como externas de la pista. El objetivo es ofrecer una comprensión clara y estructurada de la arquitectura de software y la lógica de control que permiten al robot navegar de forma autónoma en entornos con obstáculos.

Los diagramas visualizan el flujo de procesamiento de información, desde la percepción del entorno mediante los sensores hasta la toma de decisiones para evitar colisiones y la ejecución de movimientos por parte de los actuadores. Se detallará la interacción entre los módulos de detección de obstáculos, los algoritmos de navegación y la manipulación de los sistemas de propulsión y dirección.

Esta representación gráfica facilitará el entendimiento de la secuencia lógica y las interdependencias entre los componentes de software, proporcionando una visión integral del funcionamiento autónomo del robot.

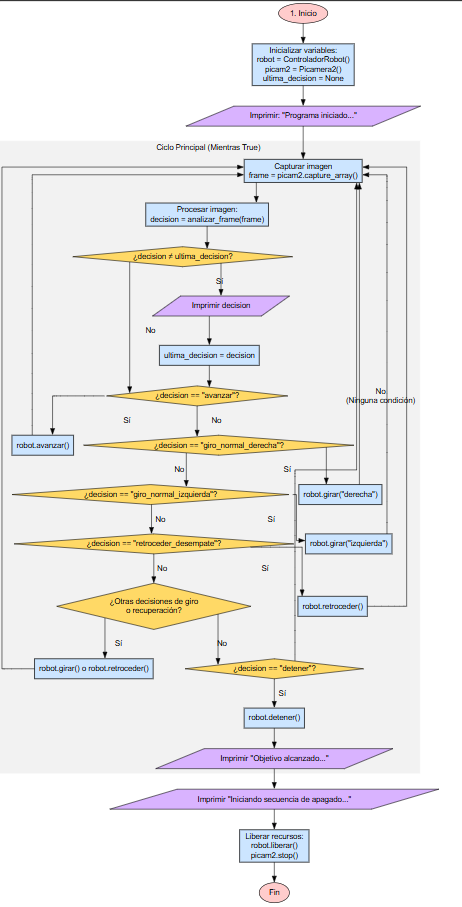
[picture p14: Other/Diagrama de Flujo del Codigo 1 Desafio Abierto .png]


---
# IMAGENES DEL VEHICULO/ROBOT

A continuación, se presentan las figuras que ilustran el prototipo de nuestro robot en su estado actual de desarrollo. Estas imágenes han sido seleccionadas para ofrecer una perspectiva clara de la implementación del diseño mecánico y la integración de los componentes clave. Se podra apreciar en como se jerarquizony se organizaron los componenetes en el chasis del robot.

---

# *Parte de Arriba* 

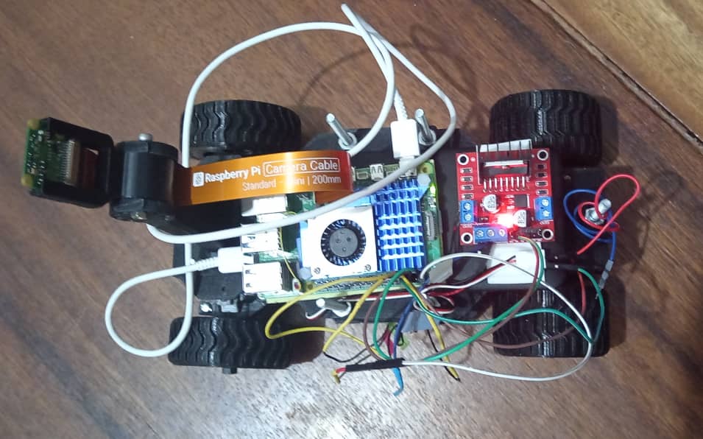
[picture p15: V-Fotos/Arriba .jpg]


---

# *Parte de abajo*

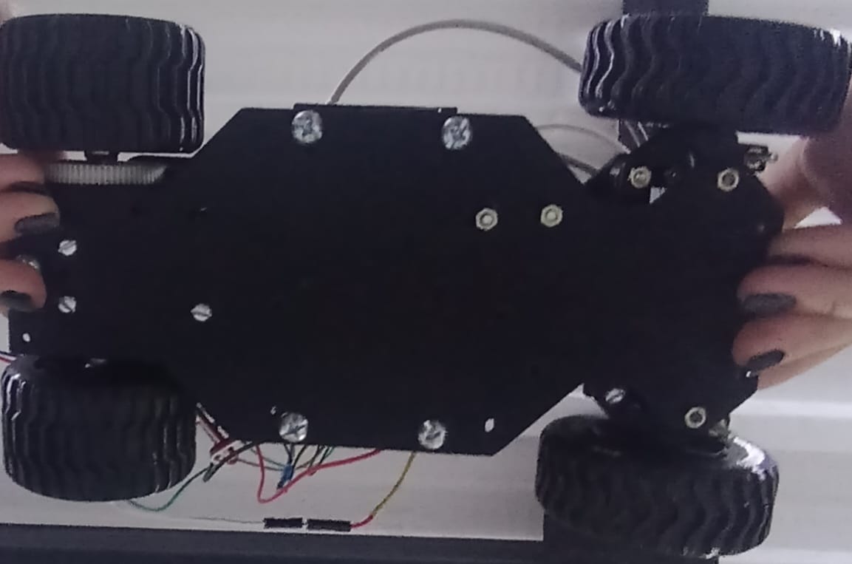
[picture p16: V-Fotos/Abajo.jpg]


---

# *Parte de Adelante* 
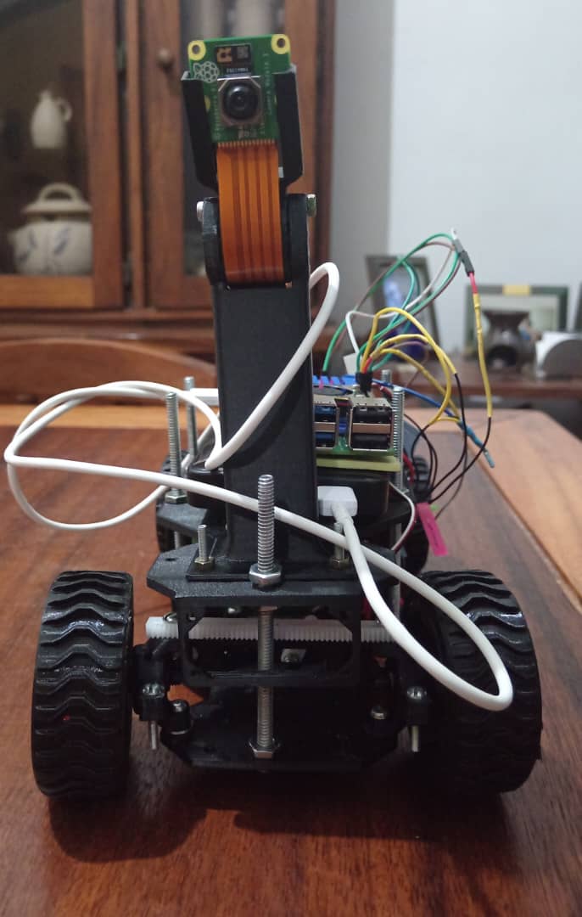
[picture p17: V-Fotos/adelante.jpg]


---

# *Parte de Atras*

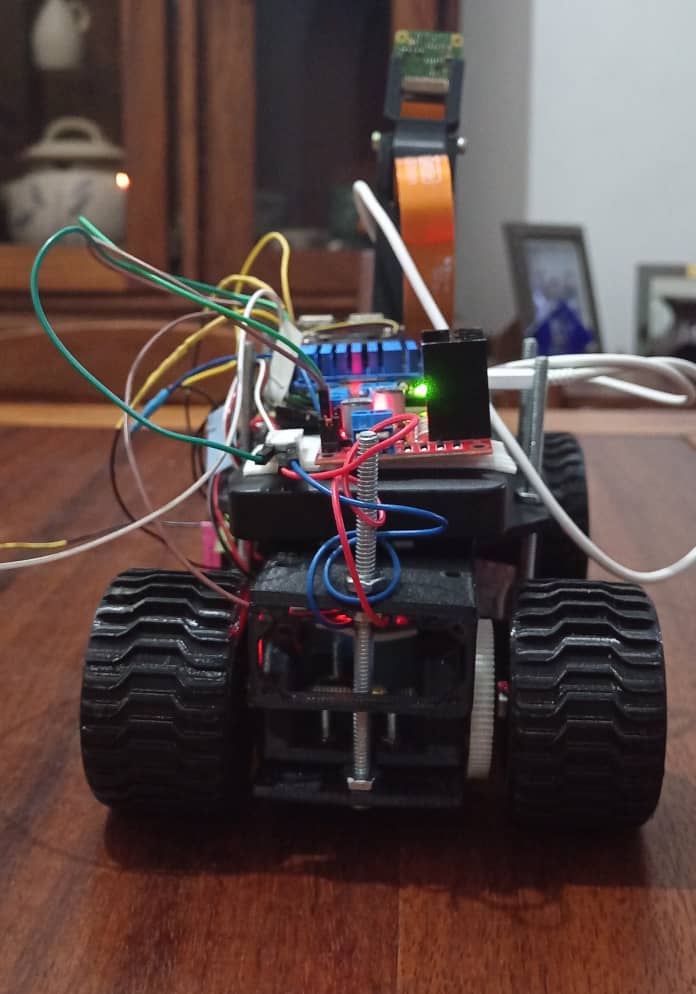
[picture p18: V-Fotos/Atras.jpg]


---

# *Parte Dreceha*
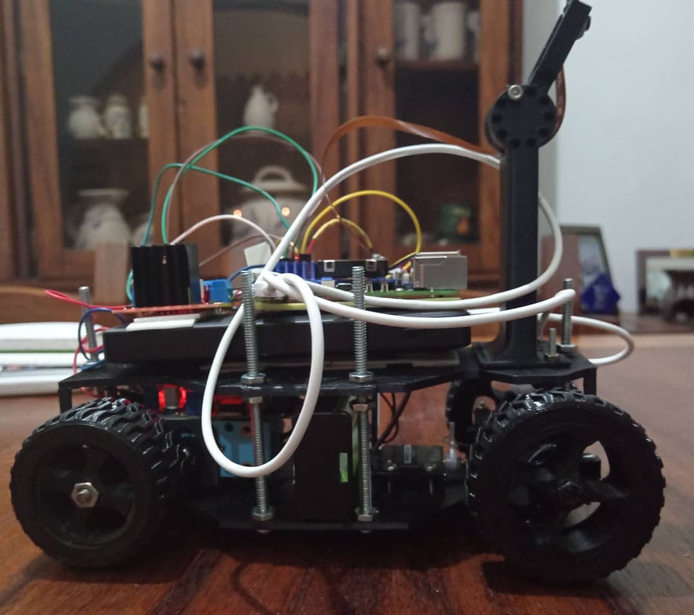
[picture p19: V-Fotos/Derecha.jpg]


---

# *Parte Izquierda*
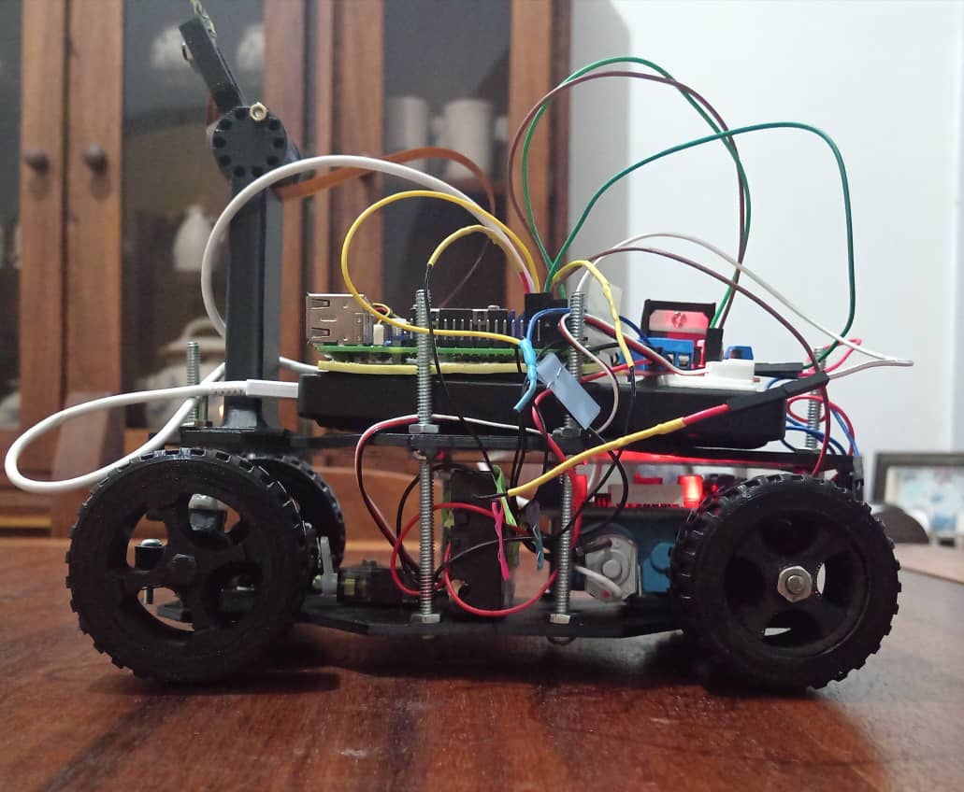
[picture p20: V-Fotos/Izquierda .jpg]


---

## 🧠 Estrategias Planteadas para Resolver los Retos

En esta sección, compartimos las metodologías y enfoques innovadores que hemos diseñado para superar los desafíos propuestos en la competencia WRO 2025.

---
# Codigo del Robot/Solución de problemas

```python
# Nombre de archivo: robot_headless.py

# --- Dependencias del Proyecto ---
# time: Para manejar pausas y timeouts en la lógica de decisión.
# lgpio: Biblioteca para el control de bajo nivel de los pines GPIO en la Raspberry Pi.
# cv2 (OpenCV): El núcleo del sistema de visión por computador para procesamiento de imágenes.
# numpy: Para la manipulación eficiente de arrays, fundamental en el procesamiento de imágenes con OpenCV.
# picamera2: La biblioteca oficial para interactuar con el módulo de cámara de la Raspberry Pi.
# libcamera.controls: Para acceder a los controles específicos del framework de la cámara.
import time
import lgpio
import cv2
import numpy as np
from picamera2 import Picamera2
from libcamera import controls

# ===================================================================================
# CLASE DEL CONTROLADOR DEL ROBOT
# ===================================================================================
# Esta clase abstrae toda la interacción con el hardware (motor DC y servomotor).
# Su propósito es ofrecer una API de alto nivel (ej: avanzar, girar) al resto del
# programa, ocultando la complejidad del manejo de señales PWM y GPIO.
class ControladorRobot:
    def _init_(self):
        # --- Configuración de Hardware ---
        # Mapeo de pines GPIO a funciones del hardware (Puente H para motor y servo).
        self.IN1_PIN, self.IN2_PIN, self.ENA_PIN = 2, 3, 18
        self.SERVO_PIN = 14
        # Calibración del servo: Rango del ciclo de trabajo (duty cycle) para los 0-180 grados.
        self.SERVO_MIN_DUTY, self.SERVO_MAX_DUTY = 2.5, 12.5
        # Frecuencia del PWM para el motor DC. Una frecuencia alta (>100Hz) evita el zumbido audible.
        self.MOTOR_PWM_FREQ = 500
        # Handle para la conexión con el chip GPIO, se inicializa en None.
        self.h_gpio = None
        
        # --- Variables de Estado del Robot ---
        # Estos atributos mantienen el contexto del robot entre iteraciones del bucle principal.
        self.modo_pista = "indefinido"  # 'horario' o 'antihorario'
        self.contador_vueltas = 0
        self.vueltas_objetivo = 20
        # Flag para el detector de flanco ascendente (detectar la línea una sola vez por pasada).
        self.linea_detectada_anteriormente = False
        
        # --- Máquina de Estados para la Maniobra de Desempate ---
        # Gestiona la secuencia de evasión cuando ambos sensores detectan un obstáculo.
        self.estado_giro_desempate = None  # e.g., 'retrocediendo', 'buscando', 'recuperando'
        self.tiempo_inicio_estado = 0
        self.direccion_futuro_giro = None

    def inicializar(self):
        """Abre la conexión con el chip GPIO, reclama los pines como salida y resetea el estado del robot."""
        self.h_gpio = lgpio.gpiochip_open(0)
        # Reclamar pines asegura que este proceso tiene control exclusivo sobre ellos.
        lgpio.gpio_claim_output(self.h_gpio, self.IN1_PIN); lgpio.gpio_claim_output(self.h_gpio, self.IN2_PIN); lgpio.gpio_claim_output(self.h_gpio, self.ENA_PIN); lgpio.gpio_claim_output(self.h_gpio, self.SERVO_PIN)
        # Establece un estado inicial conocido y seguro: robot detenido y ruedas centradas.
        self.detener(); self.centrar_direccion()
        print("[Controlador] Inicializado.")

    def set_modo_pista(self, modo):
        """Fija el modo de la pista (horario/antihorario) una única vez al detectar la primera línea de color."""
        if self.modo_pista == "indefinido": self.modo_pista = modo; print(f"### MODO DE PISTA FIJADO: {self.modo_pista.upper()} ###")

    def detener(self):
        """Corta la energía del motor estableciendo el PWM a 0."""
        if self.h_gpio: lgpio.gpio_write(self.h_gpio, self.IN1_PIN, 0); lgpio.gpio_write(self.h_gpio, self.IN2_PIN, 0); lgpio.tx_pwm(self.h_gpio, self.ENA_PIN, self.MOTOR_PWM_FREQ, 0)

    def mover(self, direccion, velocidad=100):
        """Controla el motor DC. Modifica la dirección (Puente H) y la velocidad (PWM)."""
        if self.h_gpio:
            velocidad = max(0, min(100, velocidad))  # Sanitiza la entrada de velocidad al rango [0, 100].
            # Lógica del Puente-H: IN1 y IN2 en estados opuestos para girar.
            if direccion == 1: lgpio.gpio_write(self.h_gpio, self.IN1_PIN, 0); lgpio.gpio_write(self.h_gpio, self.IN2_PIN, 1)  # Adelante
            elif direccion == -1: lgpio.gpio_write(self.h_gpio, self.IN1_PIN, 1); lgpio.gpio_write(self.h_gpio, self.IN2_PIN, 0) # Atrás
            # La velocidad se controla mediante el ciclo de trabajo del PWM en el pin ENA.
            lgpio.tx_pwm(self.h_gpio, self.ENA_PIN, self.MOTOR_PWM_FREQ, velocidad)
    
    def _establecer_angulo_servo(self, duty_cycle):
        """Función interna para enviar el comando PWM de bajo nivel al servomotor."""
        if self.h_gpio: lgpio.tx_pwm(self.h_gpio, self.SERVO_PIN, 50, duty_cycle) # Frecuencia estándar para servos es 50Hz.

    def girar_direccion(self, angulo):
        """Convierte un ángulo en grados (0-180) a su correspondiente ciclo de trabajo PWM."""
        if not (0 <= angulo <= 180): return
        # Mapeo lineal del rango de ángulos al rango de duty cycle del servo.
        duty = self.SERVO_MIN_DUTY + (angulo / 180.0) * (self.SERVO_MAX_DUTY - self.SERVO_MIN_DUTY)
        self._establecer_angulo_servo(duty)

    # --- Métodos de Abstracción de Alto Nivel ---
    def centrar_direccion(self): self.girar_direccion(85)
    def avanzar(self, velocidad): self.centrar_direccion(); self.mover(1, velocidad)
    def retroceder(self, velocidad): self.centrar_direccion(); self.mover(-1, velocidad)

    def girar(self, lado, velocidad_giro, angulo_giro=45):
        """Combina un giro de dirección y un movimiento hacia adelante para realizar un giro."""
        if lado == "izquierda": self.girar_direccion(min(90 + angulo_giro, 180))
        elif lado == "derecha": self.girar_direccion(max(90 - angulo_giro, 0))
        self.mover(1, velocidad_giro)

    def liberar(self):
        """Detiene el robot y libera los recursos GPIO. Crucial para un apagado limpio."""
        if self.h_gpio: self.detener(); self._establecer_angulo_servo(0); lgpio.gpiochip_close(self.h_gpio); print("[Controlador] GPIO limpio y robot detenido.")

# ===================================================================================
# FUNCIÓN DE DETECCIÓN DE COLOR
# ===================================================================================
def detectar_colores(frame_bgr):
    """Realiza la segmentación de colores en el espacio HSV para aislar los elementos de interés."""
    # Conversión a HSV (Hue, Saturation, Value) porque es más robusto a cambios de iluminación que BGR.
    hsv = cv2.cvtColor(frame_bgr, cv2.COLOR_BGR2HSV)
    # Definición de los rangos de color para crear máscaras booleanas.
    lower_black = np.array([0, 0, 0]); upper_black = np.array([180, 255, 85])
    lower_orange_hsv = np.array([5, 120, 150]); upper_orange_hsv = np.array([20, 255, 255])
    lower_blue_hsv = np.array([100, 120, 100]); upper_blue_hsv = np.array([120, 255, 255])
    # Creación de máscaras binarias donde los píxeles blancos representan el color detectado.
    mask_black = cv2.inRange(hsv, lower_black, upper_black)
    mask_orange = cv2.inRange(hsv, lower_orange_hsv, upper_orange_hsv)
    mask_blue = cv2.inRange(hsv, lower_blue_hsv, upper_blue_hsv)
    # Aplicación de una operación morfológica de apertura para eliminar ruido (pequeños puntos de color aislados).
    kernel = np.ones((5, 5), np.uint8)
    mask_orange = cv2.morphologyEx(mask_orange, cv2.MORPH_OPEN, kernel)
    mask_blue = cv2.morphologyEx(mask_blue, cv2.MORPH_OPEN, kernel)
    return mask_black, mask_orange, mask_blue

# ===================================================================================
# FUNCIÓN DE ANÁLISIS DE FRAME
# ===================================================================================
# Esta es la función principal de lógica. Recibe un frame y el objeto robot (su estado)
# y devuelve una única decisión de alto nivel (ej: "avanzar").
def analizar_frame(frame, robot):
    height, width, _ = frame.shape

    # Condición de terminación del programa.
    if robot.contador_vueltas >= robot.vueltas_objetivo:
        return "detener"

    # --- Definición de Regiones de Interés (ROI) ---
    # Se enfocan en áreas específicas del frame para optimizar y simplificar el análisis.
    ROI_OBSTACULOS_Y_START = int(height * 0.60)
    ROI_OBSTACULOS_Y_END = height
    ROI_LINEA_Y_START = int(height * 0.85)
    
    # --- Lógica de Conteo de Vueltas (usando la ROI inferior) ---
    roi_linea = frame[ROI_LINEA_Y_START:height, :]
    _, mask_orange, mask_blue = detectar_colores(roi_linea)
    # Se considera una línea detectada si el número de píxeles no-cero supera un umbral.
    linea_naranja_detectada = cv2.countNonZero(mask_orange) > 500
    linea_azul_detectada = cv2.countNonZero(mask_blue) > 500
    
    # Fija el modo de la pista basado en la primera línea de color que detecta.
    if robot.modo_pista == "indefinido":
        if linea_naranja_detectada: robot.set_modo_pista("horario")
        elif linea_azul_detectada: robot.set_modo_pista("antihorario")
    
    # Comprueba si la línea del modo actual está visible.
    linea_del_modo_detectada = (robot.modo_pista == "horario" and linea_naranja_detectada) or \
                                 (robot.modo_pista == "antihorario" and linea_azul_detectada)
        
    # Implementa un detector de flanco: cuenta la vuelta solo en la transición de no ver a ver la línea.
    if linea_del_modo_detectada and not robot.linea_detectada_anteriormente:
        robot.contador_vueltas += 1
        print(f"¡VUELTA {robot.contador_vueltas} / {robot.vueltas_objetivo} REGISTRADA!")
    robot.linea_detectada_anteriormente = linea_del_modo_detectada
    
    # --- Lógica de Detección de Obstáculos (usando la ROI central/inferior) ---
    roi_obstaculos = frame[ROI_OBSTACULOS_Y_START:ROI_OBSTACULOS_Y_END, :]
    mask_black, _, _ = detectar_colores(roi_obstaculos)
    
    # Divide la ROI de obstáculos en dos mitades para detectar de qué lado está el obstáculo.
    PUNTO_DIVISION = roi_obstaculos.shape[1] // 2
    area_total_lado = (PUNTO_DIVISION * roi_obstaculos.shape[0])
    # Calcula la densidad de píxeles negros en cada lado.
    porcentaje_izquierdo = (cv2.countNonZero(mask_black[:, :PUNTO_DIVISION]) / area_total_lado) * 100
    porcentaje_derecho = (cv2.countNonZero(mask_black[:, PUNTO_DIVISION:]) / area_total_lado) * 100
    
    hay_obstaculo_izq = porcentaje_izquierdo > 13
    hay_obstaculo_der = porcentaje_derecho > 13

    # --- Lógica de Decisión Jerárquica ---
    decision = "avanzar"  # Decisión por defecto.
    
    # 1. Se prioriza la máquina de estados de desempate si está activa.
    if robot.estado_giro_desempate is not None:
        # Lógica secuencial basada en tiempo para la maniobra de evasión.
        if robot.estado_giro_desempate == "retrocediendo_para_desempate":
            if time.time() - robot.tiempo_inicio_estado > TIMEOUT_RETROCESO_SEGS:
                robot.estado_giro_desempate = "buscando"
                robot.tiempo_inicio_estado = time.time()
            else:
                decision = "retroceder_desempate"
        elif robot.estado_giro_desempate == "buscando":
            if time.time() - robot.tiempo_inicio_estado > TIMEOUT_GIRO_DESEMPATE_SEGS:
                robot.estado_giro_desempate = "recuperando"
                robot.tiempo_inicio_estado = time.time()
            else:
                decision = "girando_desempate_derecha" if robot.direccion_futuro_giro == "derecha" else "girando_desempate_izquierda"
        elif robot.estado_giro_desempate == "recuperando":
            if time.time() - robot.tiempo_inicio_estado > TIMEOUT_RECUPERACION_SEGS:
                robot.estado_giro_desempate = None # Fin de la maniobra
                decision = "avanzar"
            else:
                decision = "giro_recuperacion_izquierda" if robot.direccion_futuro_giro == "derecha" else "giro_recuperacion_derecha"
    # 2. Si no hay desempate, se evalúa la condición de obstáculo frontal.
    elif hay_obstaculo_izq and hay_obstaculo_der:
        # Activa la máquina de estados de desempate.
        robot.estado_giro_desempate = "retrocediendo_para_desempate"
        robot.direccion_futuro_giro = "derecha" if robot.modo_pista == "horario" else "izquierda"
        robot.tiempo_inicio_estado = time.time()
        decision = "retroceder_desempate"
    # 3. Se evalúan los obstáculos laterales.
    elif hay_obstaculo_izq:
        decision = "giro_normal_derecha"
    elif hay_obstaculo_der:
        decision = "giro_normal_izquierda"

    return decision

# ===================================================================================
# CÓDIGO PRINCIPAL - MODO HEADLESS
# ===================================================================================
# Punto de entrada del programa.
robot = ControladorRobot()

# --- Hiperparámetros de Comportamiento ---
# Externalizar estos valores facilita el ajuste y la calibración del robot sin tocar la lógica principal.
VELOCIDAD_AVANCE = 50
VELOCIDAD_GIRO = 40
VELOCIDAD_RETROCESO = 50
ANGULO_GIRO_NORMAL = 45
ANGULO_GIRO_DESEMPATE = 50
ANGULO_GIRO_RECUPERACION = 50
TIMEOUT_RETROCESO_SEGS = 0.8
TIMEOUT_GIRO_DESEMPATE_SEGS = 2.4
TIMEOUT_RECUPERACION_SEGS = 0

ultima_decision = None

try:
    # --- Fase de Inicialización ---
    robot.inicializar()
    picam2 = Picamera2()
    # Configuración de la cámara: es crucial para obtener imágenes consistentes.
    # Se deshabilitan controles automáticos (foco, exposición, balance de blancos) para
    # asegurar que las condiciones de imagen no varíen y afecten la detección de color.
    config = picam2.create_video_configuration(main={"size": (640, 480)}, controls={"AfMode": controls.AfModeEnum.Manual, "LensPosition": 1.5, "AeEnable": True, "AwbEnable": True, "Brightness": 0.05, "Contrast": 1.2, "FrameRate": 30})
    picam2.configure(config)
    picam2.start()
    print("Programa iniciado en modo headless. Presiona Ctrl+C para salir.")

    # --- Bucle Principal de Control ---
    # Este es el corazón del programa: un ciclo infinito de percibir-planificar-actuar.
    while True:
        # 1. Percibir: Captura un frame de la cámara.
        frame_bgr = cv2.cvtColor(picam2.capture_array(), cv2.COLOR_RGB2BGR)
        
        # 2. Planificar: Llama a la función de análisis para obtener una decisión.
        decision = analizar_frame(frame_bgr, robot)

        # Imprime la acción solo cuando cambia para no saturar la consola.
        if decision != ultima_decision:
            print(f"Acción: {decision}")
            ultima_decision = decision
        
        # 3. Actuar: Ejecuta la acción decidida a través de la API del controlador del robot.
        # Este bloque 'if/elif' actúa como un despachador que mapea la decisión (string) a un método del objeto robot.
        if decision == "avanzar":
            robot.avanzar(VELOCIDAD_AVANCE)
        elif decision == "giro_normal_derecha":
            robot.girar("derecha", VELOCIDAD_GIRO, angulo_giro=ANGULO_GIRO_NORMAL)
        elif decision == "giro_normal_izquierda":
            robot.girar("izquierda", VELOCIDAD_GIRO, angulo_giro=ANGULO_GIRO_NORMAL)
        elif decision == "retroceder_desempate":
            robot.retroceder(VELOCIDAD_RETROCESO)
        elif decision == "girando_desempate_derecha":
            robot.girar("derecha", VELOCIDAD_GIRO, angulo_giro=ANGULO_GIRO_DESEMPATE)
        elif decision == "girando_desempate_izquierda":
            robot.girar("izquierda", VELOCIDAD_GIRO, angulo_giro=ANGULO_GIRO_DESEMPATE)
        elif decision == "giro_recuperacion_izquierda":
            robot.girar("izquierda", VELOCIDAD_GIRO, angulo_giro=ANGULO_GIRO_RECUPERACION)
        elif decision == "giro_recuperacion_derecha":
            robot.girar("derecha", VELOCIDAD_GIRO, angulo_giro=ANGULO_GIRO_RECUPERACION)
        elif decision == "detener":
            robot.detener()
            print("Objetivo de vueltas alcanzado. Deteniendo el robot.")
            break # Rompe el bucle while y termina el programa.

# Manejo de la interrupción por teclado para un cierre controlado.
except KeyboardInterrupt:
    print("\nPrograma interrumpido por el usuario (Ctrl+C).")
# El bloque 'finally' se ejecuta siempre, sin importar si hubo un error o no.
# Es el lugar ideal para la limpieza de recursos.
finally:
    print("Iniciando secuencia de apagado...")
    robot.liberar() # Libera los pines GPIO.
    if 'picam2' in locals() and picam2.started:
        picam2.stop() # Detiene la cámara.
    print("Recursos de cámara y GPIO liberados. Programa terminado.")

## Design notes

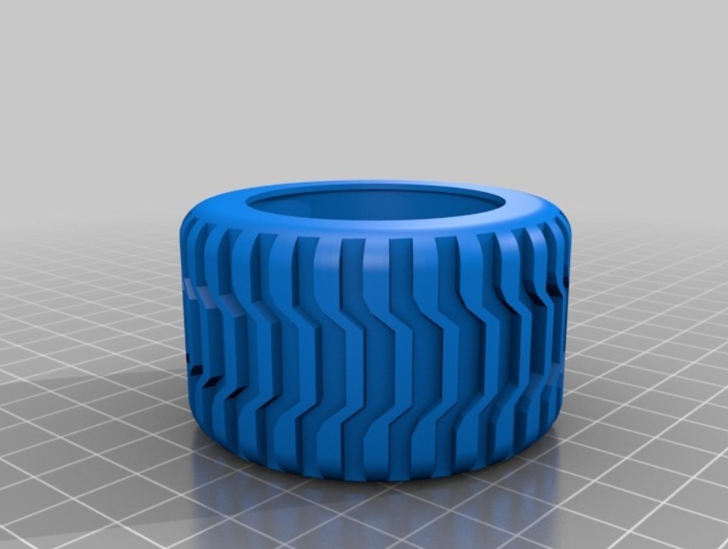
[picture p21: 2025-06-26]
Models/Elemento 4.jpg

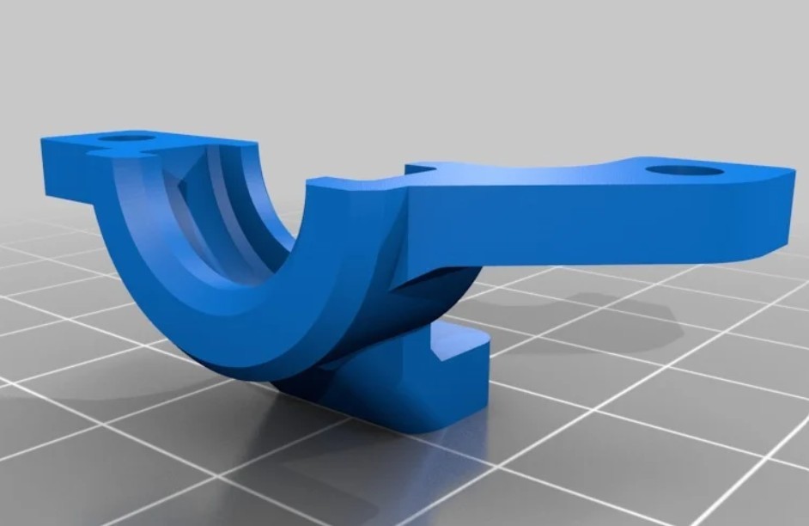
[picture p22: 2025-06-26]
Models/Elemento 5.jpg

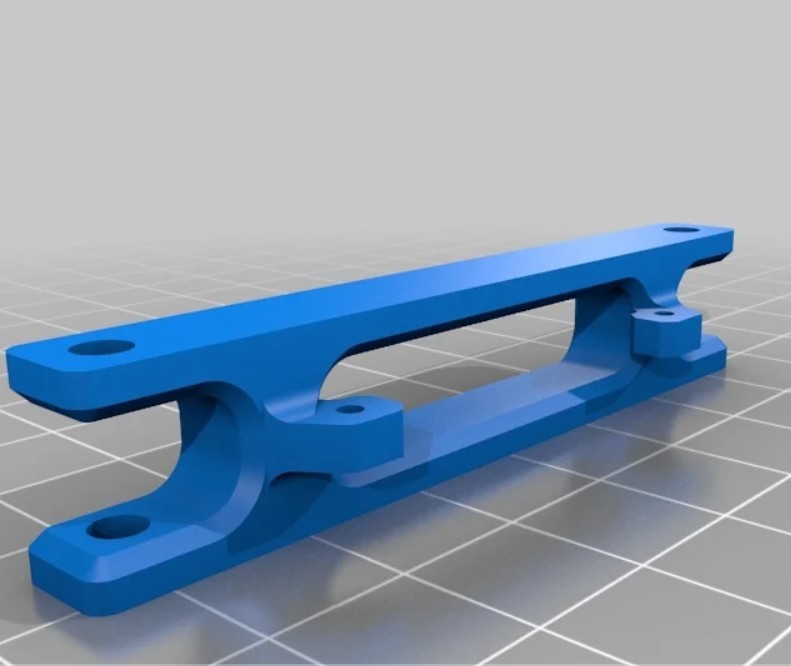
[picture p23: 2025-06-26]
Models/Elemento 6.jpg

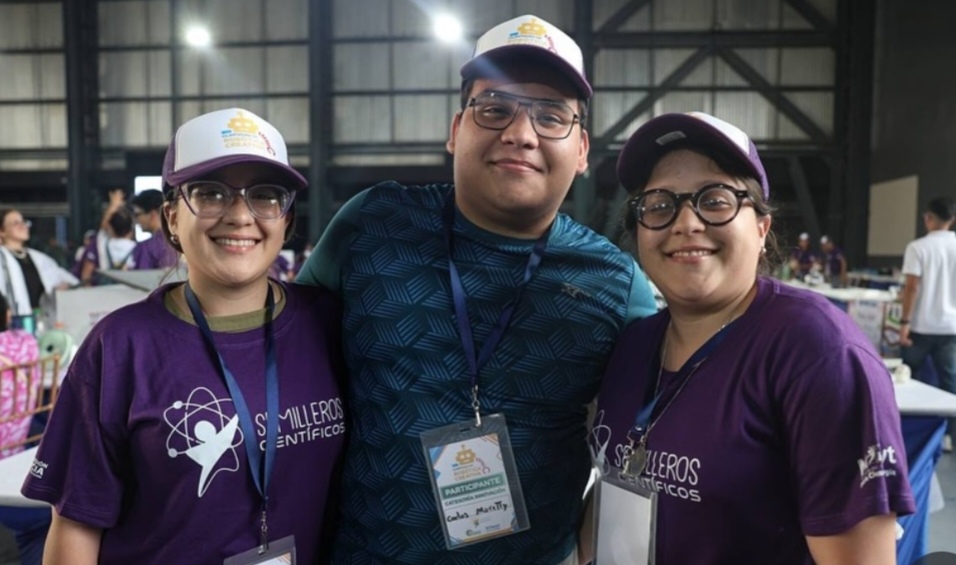
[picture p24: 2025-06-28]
T-Fotos/T-Foto.jpg

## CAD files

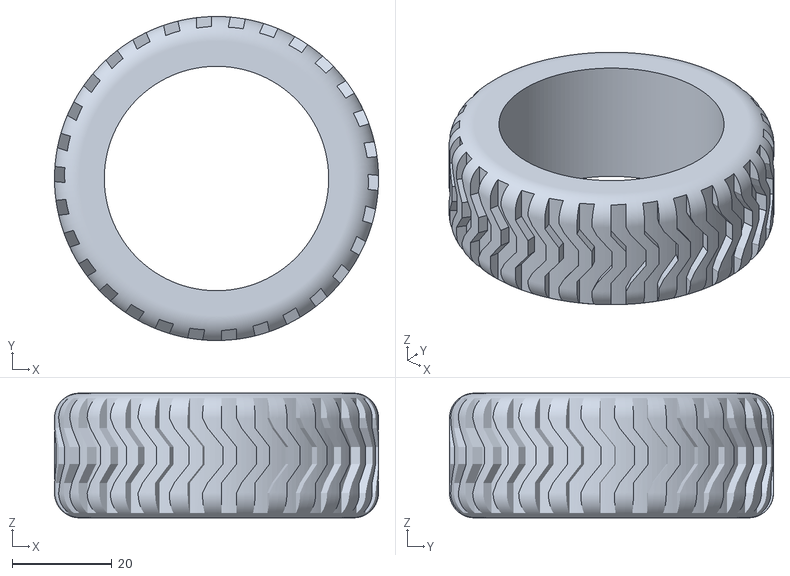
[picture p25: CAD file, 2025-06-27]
Models/Models 3D/Front_Wheel_-_Ninjaflex (1).stl
65.0 x 65.0 x 25.0

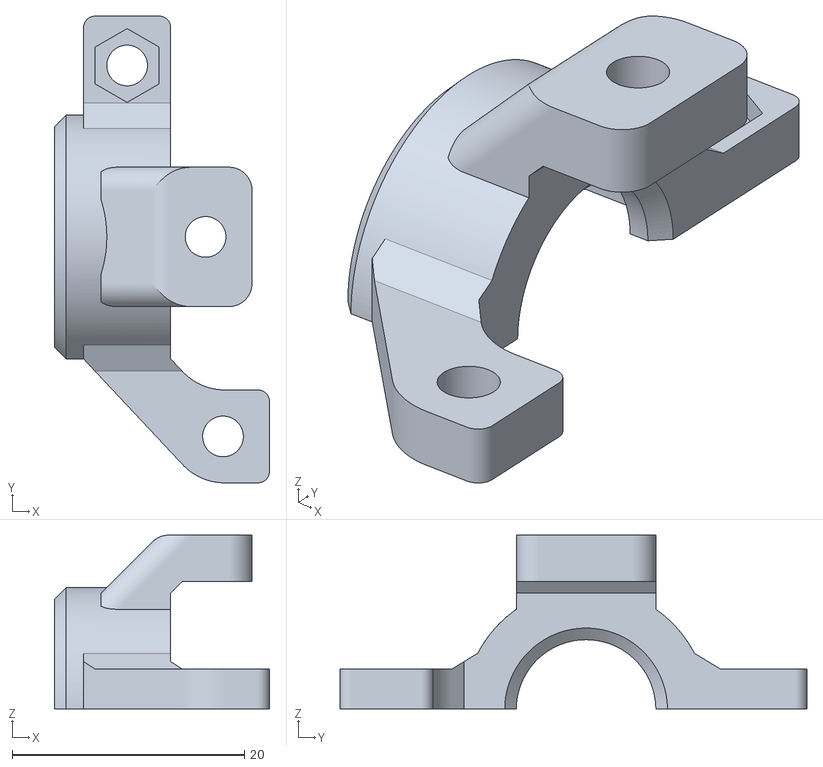
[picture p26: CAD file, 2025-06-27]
Models/Models 3D/Axle_Mount_Side_2.stl
18.5 x 40.2 x 15.0

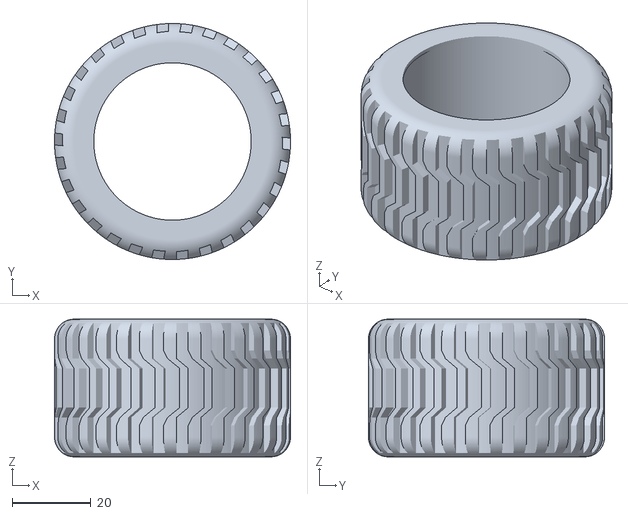
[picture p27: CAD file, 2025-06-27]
Models/Models 3D/Rear_Wheel_-_Ninjaflex (1).stl
60.0 x 60.0 x 35.0

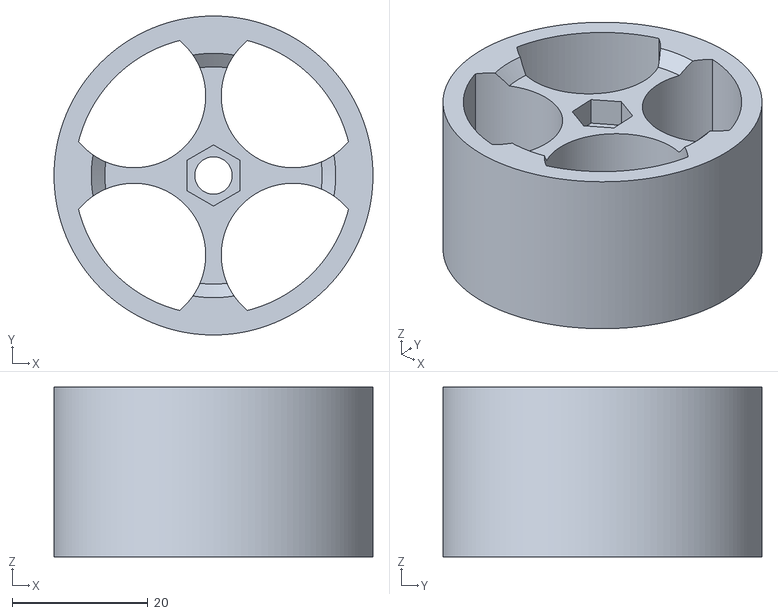
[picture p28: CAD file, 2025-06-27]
Models/Models 3D/Front_Wheel_Simple_-_PLA (1).stl
47.0 x 47.0 x 25.0

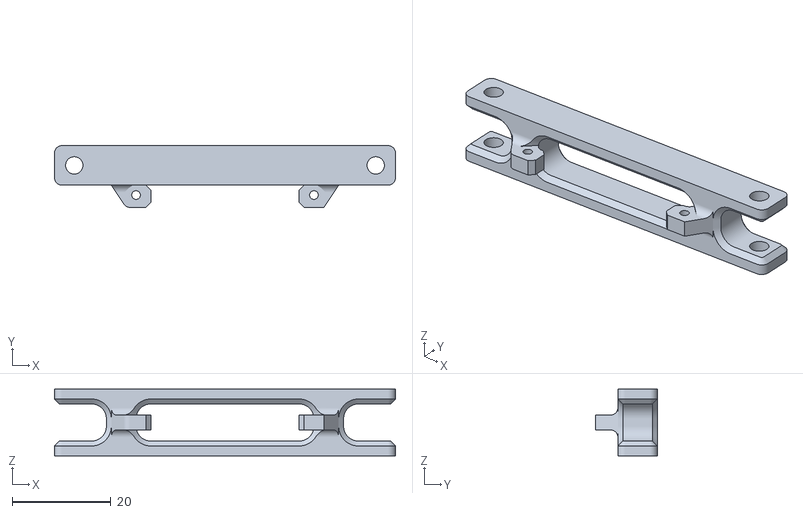
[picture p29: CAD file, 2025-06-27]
Models/Models 3D/Steering_-Rack- (1).stl
69.0 x 12.5 x 13.5

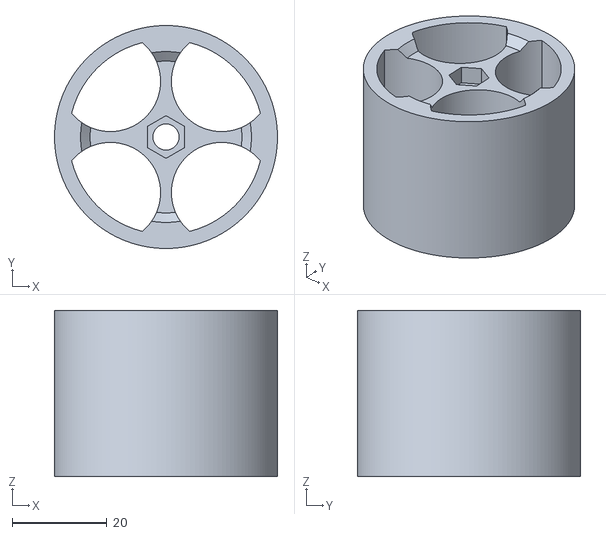
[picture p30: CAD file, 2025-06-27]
Models/Models 3D/Rear_Wheel_Simple_-_PLA.stl
47.0 x 47.0 x 35.0

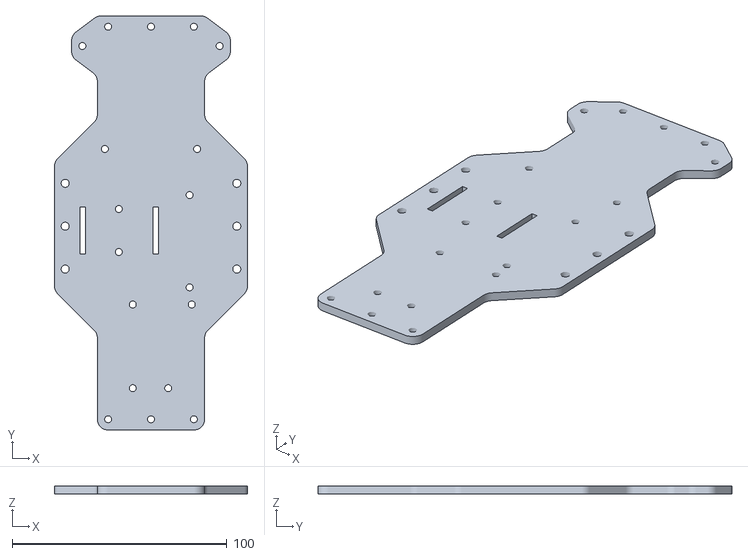
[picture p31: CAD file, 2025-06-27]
Models/Models 3D/3D_Printable_Bottom_Plate (1).stl
90.0 x 193.0 x 3.50

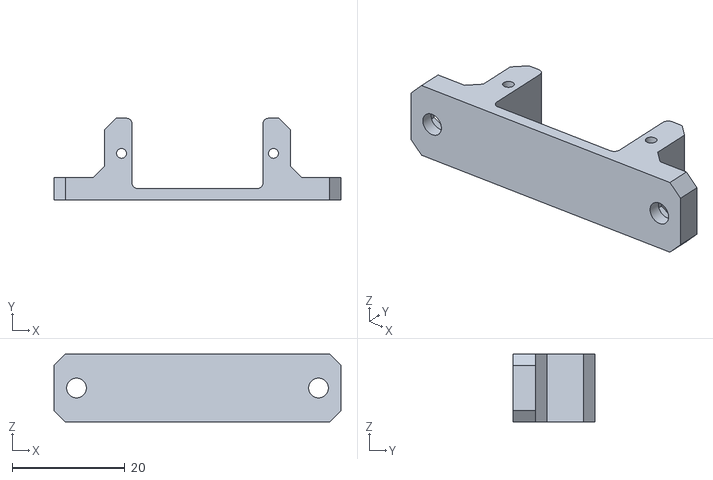
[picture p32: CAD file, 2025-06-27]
Models/Models 3D/9g_Servo_Mount.stl
51.0 x 14.5 x 12.0

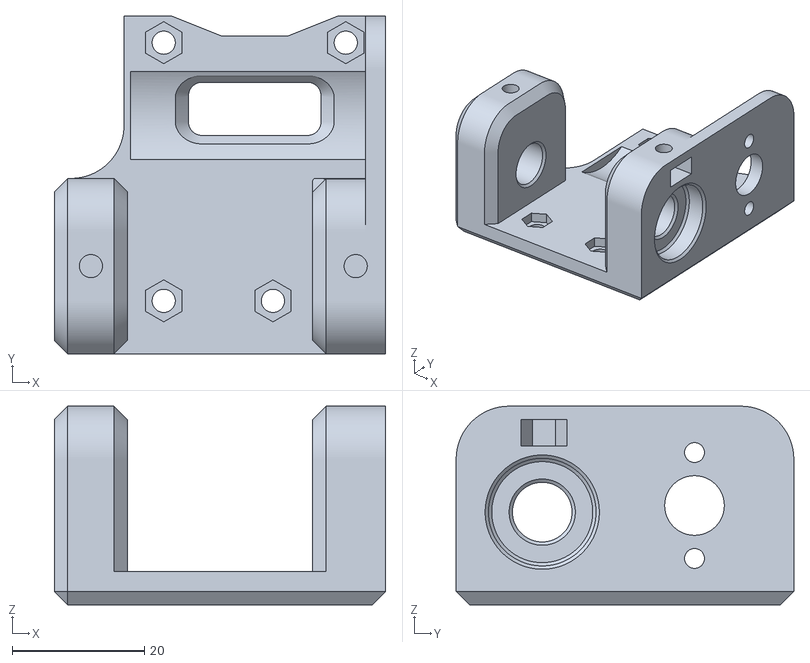
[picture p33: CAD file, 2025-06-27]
Models/Models 3D/2430_Motor_Mount.stl
50.0 x 51.0 x 30.0

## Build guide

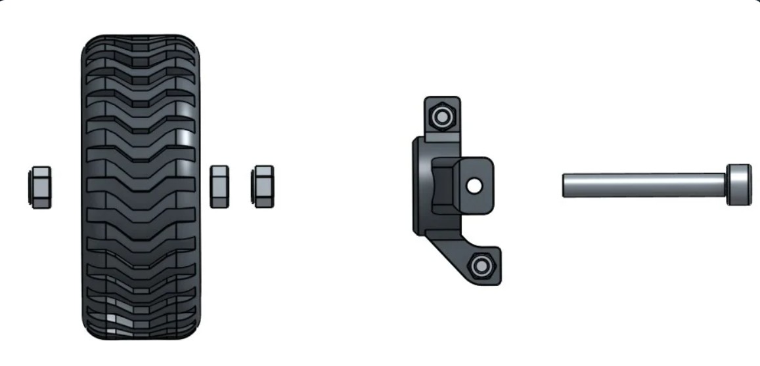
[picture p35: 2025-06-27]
Armado del Vehiculo/Piezas del armado 1 .jpg

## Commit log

2025-06-25 Motor Codificador Optico
2025-06-26 Add files via upload
    Imagenes de los Componentes Electronicos
2025-06-26 Logo e imagen de portada
2025-06-26 Logo del Equipo e Imagen de Portada
2025-06-27 Models 3D
    [2430_Motor_Mount.stl, 3D_Printable_Bottom_Plate (1).stl, 9g_Servo_Mount.stl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]
2025-06-28 Diagrama de cableado
2025-06-28 Regulador de Voltaje
2025-06-28 Regulador de Voltaje 1
2025-06-28 Diagrama de Cableado II
2025-07-06 Diagrama de Flujo de codigo
